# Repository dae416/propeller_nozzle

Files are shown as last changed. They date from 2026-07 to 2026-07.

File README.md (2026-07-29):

# Squid-Inspired Jet Nozzle Dataset

Thrust and power measurements for **24 propeller-driven jet nozzle designs**
across three generations — **32 measurements**, because every Generation 1 shape
was tested in both rigid and flexible material. Printable geometry included.

Generation 1 is a Latin-hypercube sweep of the design space. Generations 2 and 3
were proposed by a multi-objective Bayesian optimizer (ARD Matérn-5/2 GP + qEHVI)
trained on everything measured before them, maximizing thrust while minimizing
current draw.

Nozzles come in two materials, **rigid** and **flexible**. In Generation 1 each
shape was printed in both, so the same geometry appears twice. From Generation 2
on, rigid and flexible are optimized separately — each nozzle is one material
only, with its own geometry. All were measured on a dynamometer in a water tank.

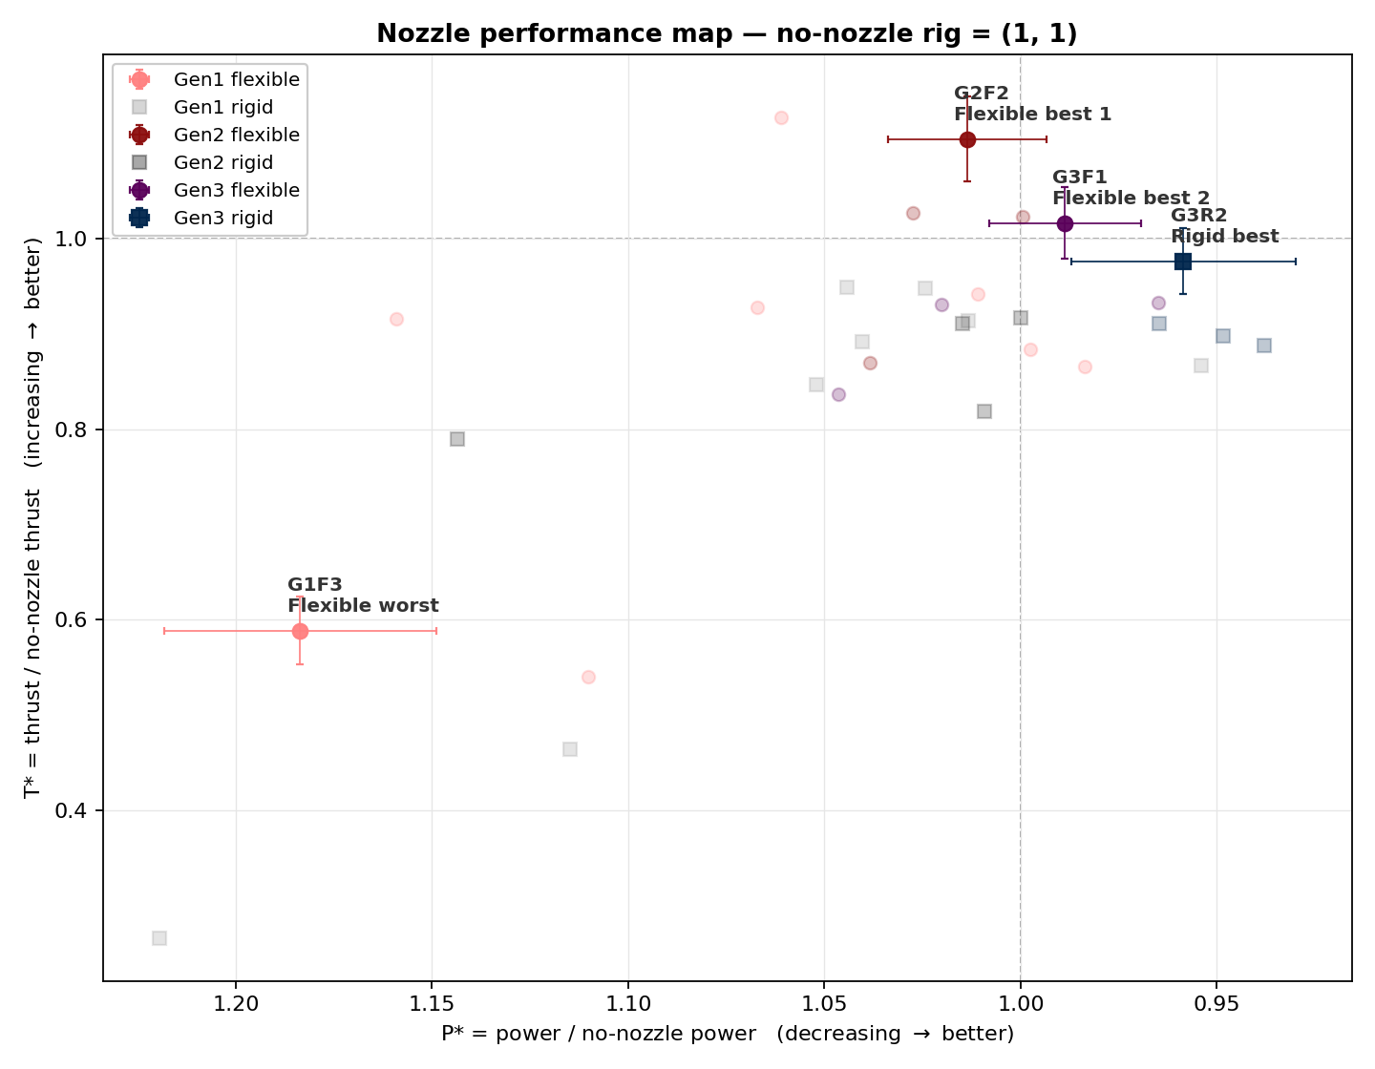
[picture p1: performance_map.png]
Nozzle performance map


The four representative shapes, with error bars over the three thrust pulses;
every other measured nozzle is behind them in faded form. Both axes are ratios
against the bare propeller, which sits at (1, 1). **Up and to the right is
better** — the power axis is reversed so that less power draw points right.
Indices for the faded points are in the results table below.

---

## Representative shapes

<table>
<tr>
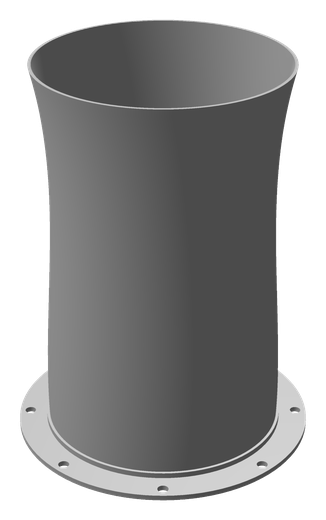
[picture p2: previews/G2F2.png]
<td width="25%" align="center"><br><b>G2F2</b><br>Flexible best 1</td>
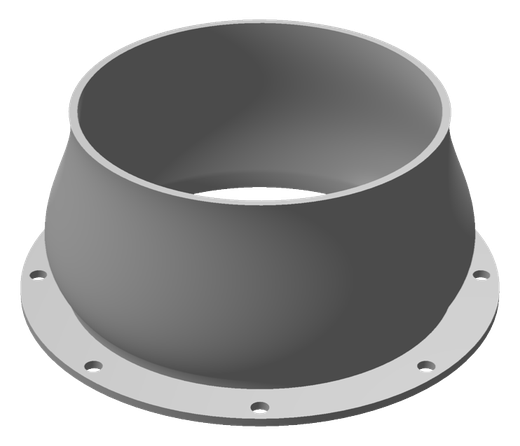
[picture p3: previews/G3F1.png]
<td width="25%" align="center"><br><b>G3F1</b><br>Flexible best 2</td>
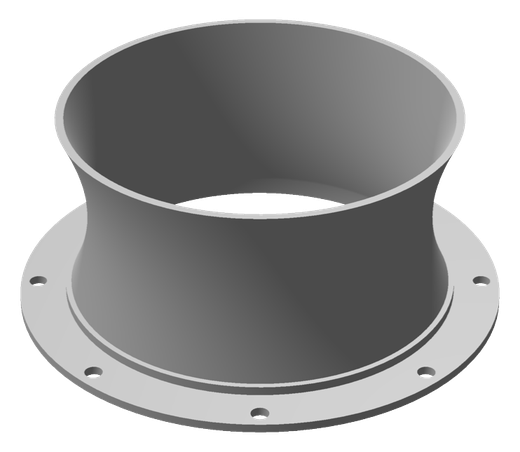
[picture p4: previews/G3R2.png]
<td width="25%" align="center"><br><b>G3R2</b><br>Rigid best</td>
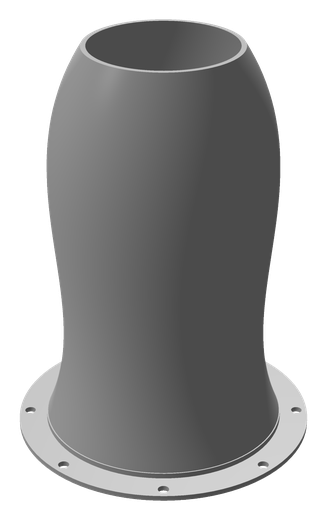
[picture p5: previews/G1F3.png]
<td width="25%" align="center"><br><b>G1F3</b><br>Flexible worst</td>
</tr>
</table>

| Index | Role | Generation | Material | Thrust vs no-nozzle | Power vs no-nozzle | STEP |
|---|---|---|---|---|---|---|
| **`G2F2`** | Flexible best 1 | 2 | Flexible | **+10.5%** ± 4.4% | **+1.4%** ± 2.0% | [`G2_F_S2.step`](STEP/G2_F_S2.step) |
| **`G3F1`** | Flexible best 2 | 3 | Flexible | **+1.7%** ± 3.8% | **-1.1%** ± 1.9% | [`G3_F_S1.step`](STEP/G3_F_S1.step) |
| **`G3R2`** | Rigid best | 3 | Rigid | **-2.3%** ± 3.4% | **-4.2%** ± 2.9% | [`G3_R_S2.step`](STEP/G3_R_S2.step) |
| **`G1F3`** | Flexible worst | 1 | Flexible | **-41.2%** ± 3.5% | **+18.4%** ± 3.5% | [`G1S3.step`](STEP/G1S3.step) |

Their shape parameters:

| Index | bulge | neck | tip_expansion | R_tip (mm) | t_bottom (mm) | t_top (mm) | L (mm) |
|---|---|---|---|---|---|---|---|
| `G2F2` | 0.9743 | 0.936 | 0.9288 | 50.2222 | 0.9466 | 1.1814 | 139.7882 |
| `G3F1` | 1.1 | 1 | 0.9167 | 46.4392 | 2 | 2 | 42.5 |
| `G3R2` | 0.8463 | 0.9246 | 0.8258 | 55.25 | 0.7 | 2 | 42.5 |
| `G1F3` | 0.8455 | 0.9322 | 0.8378 | 33.9944 | 1.5733 | 1.8579 | 145.2361 |

---

## Reading the numbers

Both metrics are ratios against the **no-nozzle** rig running in the same session:

| | meaning | good direction | 1.0 means |
|---|---|---|---|
| **T\*** | thrust ÷ no-nozzle thrust | ↑ higher | same thrust as bare propeller |
| **I\*** | current ÷ no-nozzle current | ↓ lower | same current as bare propeller |
| **P\*** | power ÷ no-nozzle power | ↓ lower | supply voltage is fixed, so P\* = I\* exactly |

**The tables below report these as percent change from the bare propeller**,
because it reads more directly: `+10.5%` thrust is T\* = 1.105, `-4.2%` power is
P\* = 0.958. So **positive thrust is good, negative power is good**. The `±` is
the standard deviation over the three pulses, also in percent. The CSVs keep the
raw ratios.

**Why normalize at all?** The rig's absolute output drifts between test sessions
by up to 20% — two Gen2 Rigid sessions measured the bare propeller at 26.9 N and
32.2 N. Yet the nozzle-to-baseline ratios in those two sessions were 0.865 and
0.853: the drift is in the rig, not in the nozzles. Dividing it out is what makes
generations comparable. Which no-nozzle run backs each session was chosen per
session by the experimenter, from the recorded data.

The consequence is that **T\* and I\* compare across the whole table, but raw
newtons would not** — which is why raw values are not published here. The
`Session` column records which no-nozzle run each row was divided by.

---

## Results

⭐ marks a representative shape. Sorted by thrust within each group.

**Gen1 Flexible**

| Index | Thrust | Power | Session | STEP |
|---|---|---|---|---|
| `G1FCylinder` | +12.8% ± 3.7% | +6.1% ± 6.8% | G1 | — |
| `G1F6` | -5.7% ± 1.5% | +1.1% ± 8.7% | G1 | [`G1S6.step`](STEP/G1S6.step) |
| `G1F2` | -7.2% ± 3.4% | +6.7% ± 5.2% | G1 | [`G1S2.step`](STEP/G1S2.step) |
| `G1F1` | -8.3% ± 8.9% | +15.9% ± 15.3% | G1 | [`G1S1.step`](STEP/G1S1.step) |
| `G1F8` | -11.6% ± 4.1% | -0.2% ± 4.1% | G1 | [`G1S8.step`](STEP/G1S8.step) |
| `G1F5` | -13.4% ± 2.2% | -1.6% ± 3.0% | G1 | [`G1S5.step`](STEP/G1S5.step) |
| `G1F3` ⭐ | -41.2% ± 3.5% | +18.4% ± 3.5% | G1 | [`G1S3.step`](STEP/G1S3.step) |
| `G1F4` | -46.0% ± 1.1% | +11.0% ± 5.2% | G1 | [`G1S4.step`](STEP/G1S4.step) |

**Gen1 Rigid**

| Index | Thrust | Power | Session | STEP |
|---|---|---|---|---|
| `G1RCylinder` | -5.0% ± 1.8% | +4.4% ± 4.7% | G1 | — |
| `G1R2` | -5.2% ± 3.0% | +2.4% ± 4.0% | G1 | [`G1S2.step`](STEP/G1S2.step) |
| `G1R5` | -8.6% ± 2.7% | +1.3% ± 5.1% | G1 | [`G1S5.step`](STEP/G1S5.step) |
| `G1R8` | -10.8% ± 2.2% | +4.0% ± 4.7% | G1 | [`G1S8.step`](STEP/G1S8.step) |
| `G1R6` | -13.3% ± 3.5% | -4.6% ± 4.6% | G1 | [`G1S6.step`](STEP/G1S6.step) |
| `G1R1` | -15.3% ± 5.0% | +5.2% ± 7.2% | G1 | [`G1S1.step`](STEP/G1S1.step) |
| `G1R4` | -53.7% ± 1.5% | +11.5% ± 1.7% | G1 | [`G1S4.step`](STEP/G1S4.step) |
| `G1R3` | -73.5% ± 0.8% | +21.9% ± 5.7% | G1 | [`G1S3.step`](STEP/G1S3.step) |

**Gen2 Flexible**

| Index | Thrust | Power | Session | STEP |
|---|---|---|---|---|
| `G2F2` ⭐ | +10.5% ± 4.4% | +1.4% ± 2.0% | G2F | [`G2_F_S2.step`](STEP/G2_F_S2.step) |
| `G2F1` | +2.8% ± 3.4% | +2.8% ± 1.1% | G2F | [`G2_F_S1.step`](STEP/G2_F_S1.step) |
| `G2F3` | +2.3% ± 0.4% | -0.0% ± 5.2% | G2F | [`G2_F_S3.step`](STEP/G2_F_S3.step) |
| `G2F4` | -13.0% ± 3.7% | +3.8% ± 3.3% | G2F | [`G2_F_S4.step`](STEP/G2_F_S4.step) |

**Gen2 Rigid**

| Index | Thrust | Power | Session | STEP |
|---|---|---|---|---|
| `G2R3` | -8.3% ± 3.7% | -0.0% ± 3.6% | G2R_S34 | [`G2_R_S3.step`](STEP/G2_R_S3.step) |
| `G2R2` | -8.9% ± 2.2% | +1.5% ± 3.8% | G2R_S12 | [`G2_R_S2.step`](STEP/G2_R_S2.step) |
| `G2R1` | -18.1% ± 1.3% | +0.9% ± 2.5% | G2R_S12 | [`G2_R_S1.step`](STEP/G2_R_S1.step) |
| `G2R4` | -21.0% ± 3.8% | +14.3% ± 2.1% | G2R_S34 | [`G2_R_S4.step`](STEP/G2_R_S4.step) |

**Gen3 Flexible**

| Index | Thrust | Power | Session | STEP |
|---|---|---|---|---|
| `G3F1` ⭐ | +1.7% ± 3.8% | -1.1% ± 1.9% | G3F | [`G3_F_S1.step`](STEP/G3_F_S1.step) |
| `G3F2` | -6.7% ± 1.8% | -3.5% ± 4.1% | G3F | [`G3_F_S2.step`](STEP/G3_F_S2.step) |
| `G3F4` | -6.9% ± 2.3% | +2.0% ± 1.0% | G3F | [`G3_F_S4.step`](STEP/G3_F_S4.step) |
| `G3F3` | -16.3% ± 3.1% | +4.6% ± 4.1% | G3F | [`G3_F_S3.step`](STEP/G3_F_S3.step) |

**Gen3 Rigid**

| Index | Thrust | Power | Session | STEP |
|---|---|---|---|---|
| `G3R2` ⭐ | -2.3% ± 3.4% | -4.2% ± 2.9% | G3R | [`G3_R_S2.step`](STEP/G3_R_S2.step) |
| `G3R1` | -8.9% ± 2.9% | -3.5% ± 2.2% | G3R | [`G3_R_S1.step`](STEP/G3_R_S1.step) |
| `G3R3` | -10.2% ± 3.6% | -5.2% ± 2.2% | G3R | [`G3_R_S3.step`](STEP/G3_R_S3.step) |
| `G3R4` | -11.2% ± 1.4% | -6.2% ± 1.5% | G3R | [`G3_R_S4.step`](STEP/G3_R_S4.step) |

---

## Files

| File | Content |
|---|---|
| [`nozzle_performance.csv`](nozzle_performance.csv) | 32 rows — the table above, machine-readable |
| [`geometry_parameters.csv`](geometry_parameters.csv) | 7 shape parameters per nozzle, same 32 rows, same `Index` |
| [`STL/`](STL) | 23 printable geometries |
| [`STEP/`](STEP) | The same 23 geometries as faceted B-rep STEP solids (see note below) |
| [`stl_to_step.py`](stl_to_step.py) | Script that regenerates `STEP/` from `STL/` |
| [`previews/`](previews) | Renders of the representative shapes |
| [`performance_map.png`](performance_map.png) | The plot at the top of this page |
| [`make_plot.py`](make_plot.py) | Script that regenerates the plot from the CSV |

### Columns

| Column | Meaning |
|---|---|
| `Index` | `G<generation><material><shape>` — e.g. `G1F3` is Generation 1, Flexible, shape 3. Joins the two CSVs 1:1 |
| `Generation` | 1–3 |
| `Type` | `R` rigid, `F` flexible |
| `Session` | Which no-nozzle run this row was normalized against; rows sharing a session are the most directly comparable |
| `T_star`, `I_star`, `P_star` | Normalized thrust, current, power (see above) |
| `*_std` | Standard deviation over the three pulses, normalized |
| `STL_File` | Geometry in `STL/` |
| `Representative` | Set for the four shapes highlighted above |

### Geometry parameters

| Parameter | Unit | Meaning |
|---|---|---|
| `bulge` | – | Mid-body radial expansion factor |
| `neck` | – | Throat contraction factor |
| `tip_expansion` | – | Outlet flare factor |
| `R_tip_mean_mm` | mm | Mean outlet radius |
| `t_bottom_mm`, `t_top_mm` | mm | Wall thickness at inlet / outlet |
| `L_mm` | mm | Nozzle length |

All nozzles share a fixed mounting interface: 85 mm inner bore, 110 mm flange,
2 mm flange thickness, 8 × ⌀4 mm bolts on a 51 mm circle.

### STEP files

The nozzles exist natively as meshes, so the `STEP/` files are **faceted B-rep
solids** — every STL triangle sewn into a closed `MANIFOLD_SOLID_BREP`
(~52 MB each). These import as solids in CATIA, SpaceClaim, NX, Creo, and
FreeCAD. An earlier revision shipped compact AP242 *tessellated* STEP
(~1.7 MB each) instead, but CATIA and SpaceClaim rejected those with
*"No B-Rep data in input file"*, so the heavy-but-universal form is committed.
`python stl_to_step.py STL/ out/` regenerates the tessellated variant if you
want the small files. Requires `pip install cadquery-ocp`.

### Flexible material — Formlabs Flexible 50A Resin

Flexible nozzles were printed in [Formlabs Flexible 50A Resin](https://formlabs.com/products/flexible-50a-resin/),
a soft translucent SLA elastomer for parts normally made of soft rubber or
silicone. Post-cured properties:

| Property | Value |
|---|---|
| **Stress at 100% elongation** | **1.7 MPa** ← the key stiffness number for these nozzles |
| Shore hardness | 55A |
| Ultimate tensile strength | 3.4 MPa |
| Stress at 50% elongation | 0.9 MPa |
| Elongation at break | 160% |
| Tear strength | 12.3 kN/m |
| Compression set (70°C, 22 h) | 3.1% |

---

## Notes

- **Only Generation 1 shares geometry between materials.** `G1R3` and `G1F3` are
  the same printed shape in different material, so they carry identical parameter
  rows and point at the same STL. Generation 2 and 3 nozzles are each a single
  material with geometry of their own — `G2F1` and `G2R1` are unrelated shapes.
  The optimizer runs one GP per material, trained only on that material's data.
- **`Cylinder`** is a plain reference tube, not an optimizer output, and has no
  STL. In flexible material it out-thrusts every shaped Generation 1 nozzle
  (T\* = 1.127) — worth knowing before reading too much into the early sweep.
- **Shape 7** of the Generation 1 sweep was never tested, so the indices skip
  from 6 to 8.
- **32 rows are 32 physical nozzles but only 24 distinct geometries.** Each
  Generation 1 shape was printed in both materials, so its 8 shapes account for
  16 rows. Generation 2 and 3 contribute 8 rows and 8 geometries each.
- **Generation 3 Rigid** numbers come from a 2026-05-06 processing run whose raw
  dynamometer files are no longer in the source project, so they cannot currently
  be recomputed from scratch.

## License

Measurement data and geometry from a DARPA-funded study of squid-inspired
propulsion. Please contact the repository owner before reuse.

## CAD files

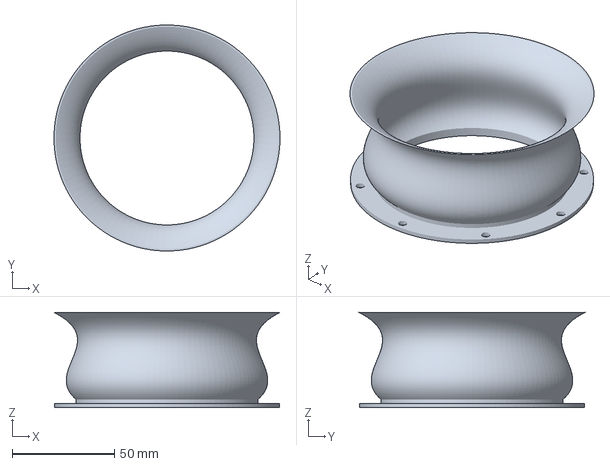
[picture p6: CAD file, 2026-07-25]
STEP/G3_R_S3.step
110.5 x 110.5 x 46.5 mm

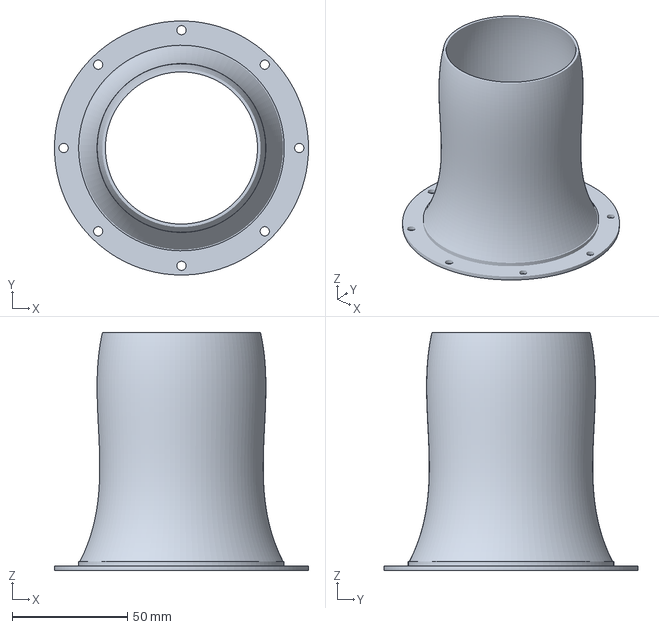
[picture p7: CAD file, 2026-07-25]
STEP/G1S1.step
110.0 x 110.0 x 103.1 mm

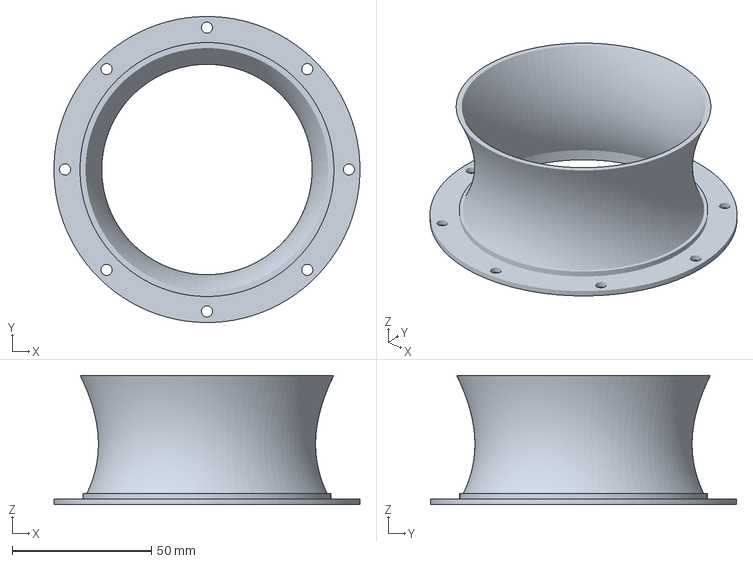
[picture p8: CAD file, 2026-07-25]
STEP/G3_R_S2.step
110.0 x 110.0 x 46.5 mm

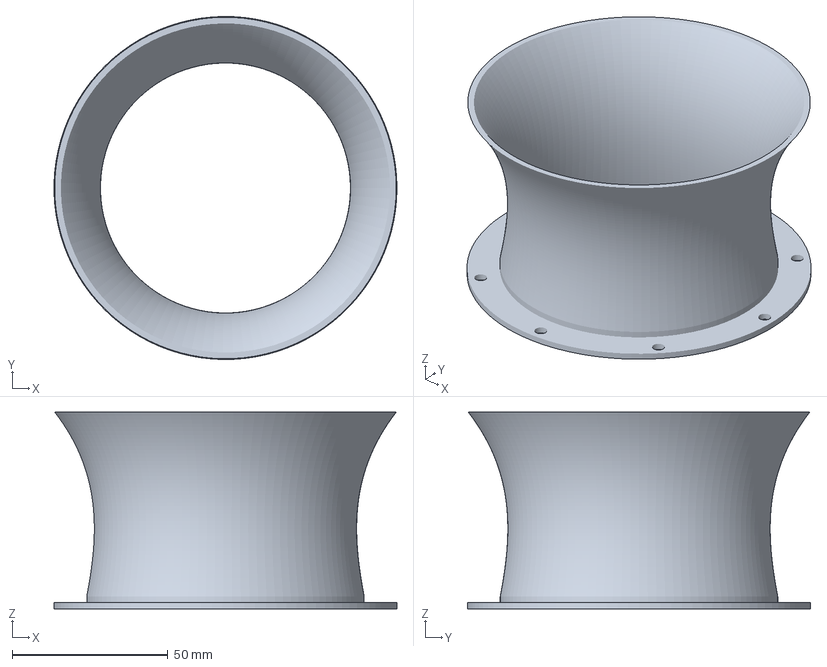
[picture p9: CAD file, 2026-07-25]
STEP/G2_F_S1.step
110.0 x 110.0 x 63.0 mm

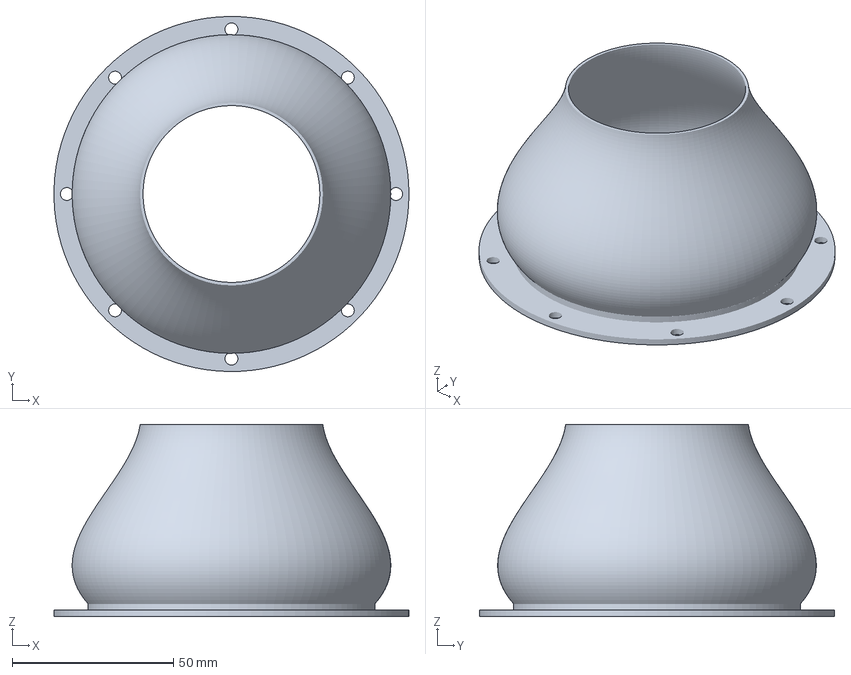
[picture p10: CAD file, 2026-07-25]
STEP/G1S4.step
110.0 x 110.0 x 59.6 mm

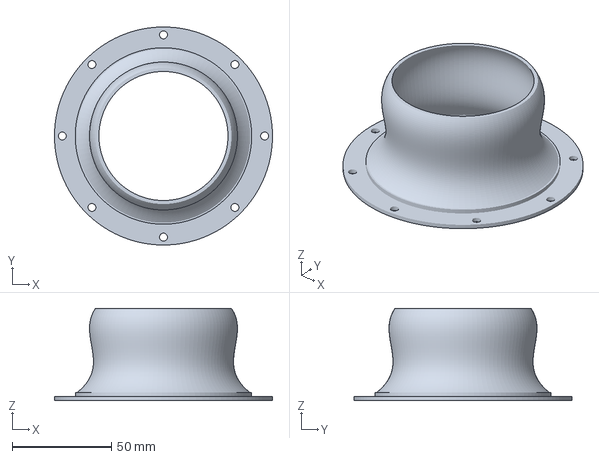
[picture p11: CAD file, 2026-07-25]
STEP/G2_R_S4.step
110.0 x 110.0 x 46.5 mm

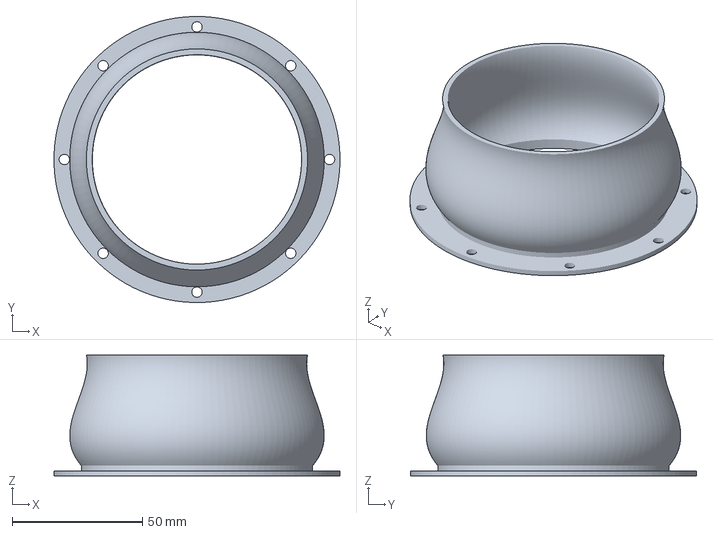
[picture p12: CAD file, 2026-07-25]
STEP/G3_F_S1.step
110.0 x 110.0 x 46.5 mm

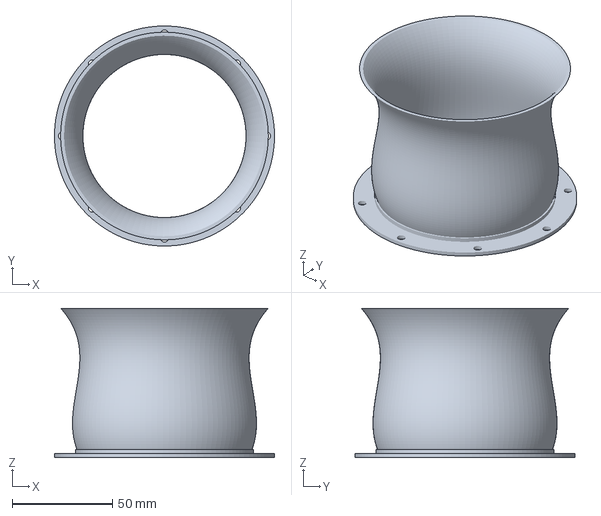
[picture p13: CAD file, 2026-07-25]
STEP/G1S6.step
110.0 x 110.0 x 74.7 mm

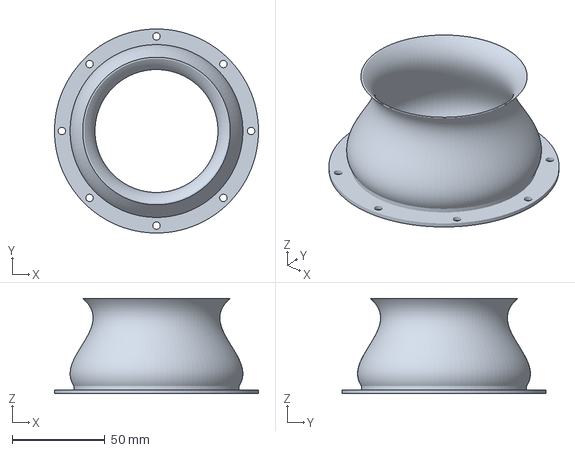
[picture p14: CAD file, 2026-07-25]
STEP/G3_R_S1.step
110.0 x 110.0 x 51.3 mm

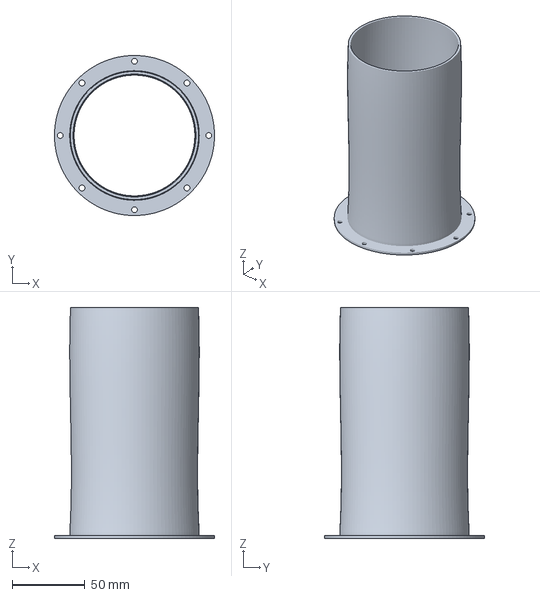
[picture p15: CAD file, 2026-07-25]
STEP/G3_F_S4.step
110.0 x 110.0 x 158.7 mm

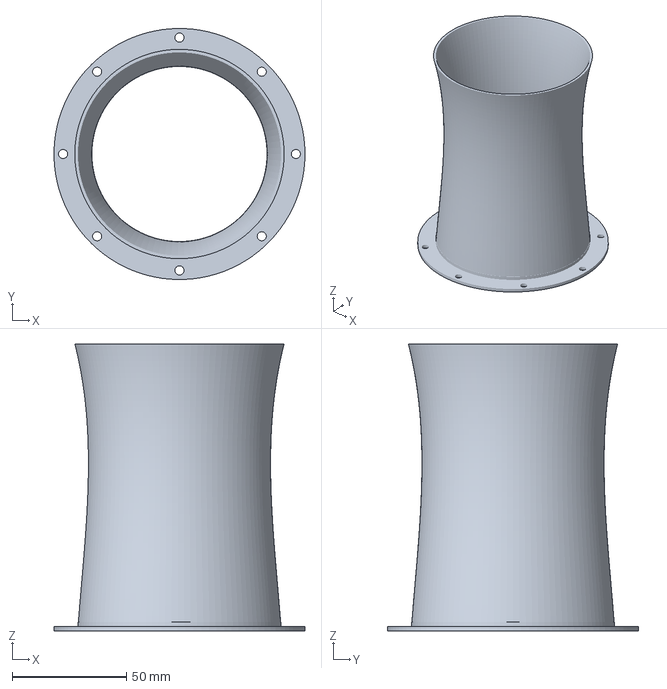
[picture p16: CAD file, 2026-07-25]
STEP/G1S8.step
110.0 x 110.0 x 125.8 mm

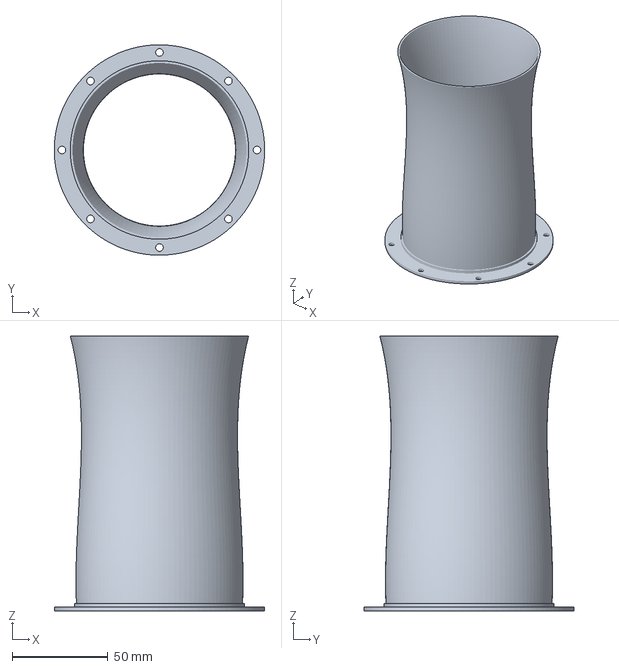
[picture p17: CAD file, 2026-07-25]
STEP/G2_F_S2.step
110.0 x 110.0 x 143.8 mm

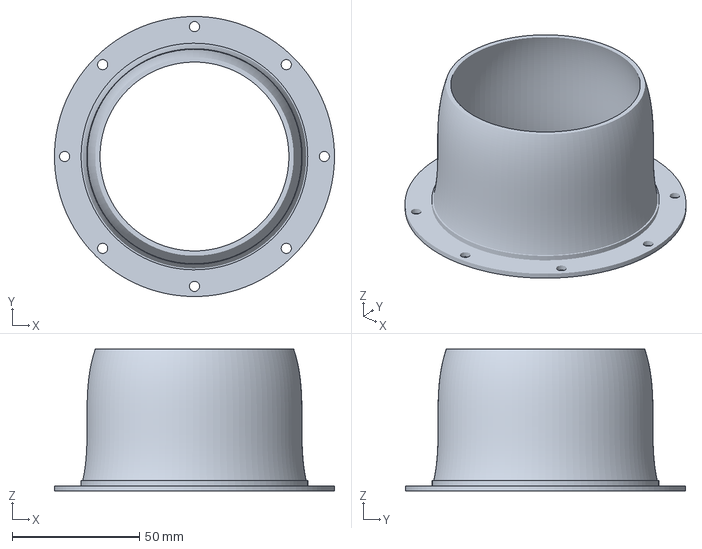
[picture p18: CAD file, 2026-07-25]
STEP/G2_F_S4.step
110.0 x 110.0 x 55.7 mm

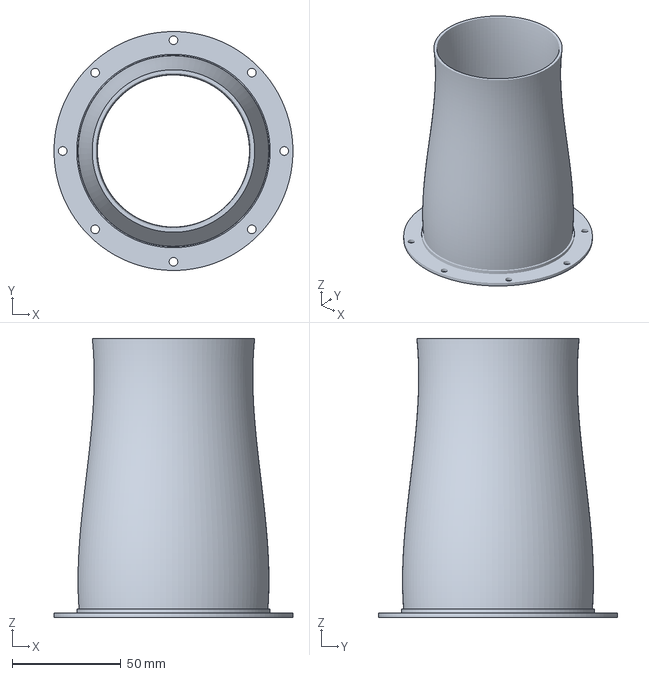
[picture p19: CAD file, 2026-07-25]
STEP/G1S5.step
110.0 x 110.0 x 128.4 mm

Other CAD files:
STEP/G2_F_S3.step
STEP/G3_F_S2.step
STEP/G3_F_S3.step
STEP/G2_R_S3.step
STEP/G1S2.step
STEP/G1S3.step
STEP/G2_R_S1.step
STEP/G2_R_S2.step
STEP/G3_R_S4.step
STL/G1S1.stl
STL/G1S2.stl
STL/G1S3.stl
STL/G1S4.stl
STL/G1S5.stl
STL/G1S6.stl
STL/G1S8.stl
STL/G2_F_S1.stl
STL/G2_F_S2.stl
STL/G2_F_S3.stl
STL/G2_F_S4.stl
STL/G2_R_S1.stl
STL/G2_R_S2.stl
STL/G2_R_S3.stl
STL/G2_R_S4.stl
STL/G3_F_S1.stl
STL/G3_F_S2.stl
STL/G3_F_S3.stl
STL/G3_F_S4.stl
STL/G3_R_S1.stl
STL/G3_R_S2.stl
STL/G3_R_S3.stl
STL/G3_R_S4.stl

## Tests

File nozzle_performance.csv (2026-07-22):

Index | Generation | Type | Session | T_star | T_star_std | I_star | I_star_std | P_star | P_star_std | STL_File | Representative
G1F1 | 1 | F | G1 | 0.9165 | 0.0894 | 1.159 | 0.1531 | 1.159 | 0.1531 | G1S1.stl
G1F2 | 1 | F | G1 | 0.9281 | 0.0344 | 1.0671 | 0.0522 | 1.0671 | 0.0522 | G1S2.stl
G1F3 | 1 | F | G1 | 0.5885 | 0.0353 | 1.1836 | 0.0347 | 1.1836 | 0.0347 | G1S3.stl | Flexible worst
G1F4 | 1 | F | G1 | 0.5398 | 0.0114 | 1.1103 | 0.0517 | 1.1103 | 0.0517 | G1S4.stl
G1F5 | 1 | F | G1 | 0.8658 | 0.0218 | 0.9837 | 0.03 | 0.9837 | 0.03 | G1S5.stl
G1F6 | 1 | F | G1 | 0.9426 | 0.0149 | 1.0109 | 0.0869 | 1.0109 | 0.0869 | G1S6.stl
G1F8 | 1 | F | G1 | 0.884 | 0.0406 | 0.9976 | 0.0408 | 0.9976 | 0.0408 | G1S8.stl
G1FCylinder | 1 | F | G1 | 1.1275 | 0.0373 | 1.0611 | 0.0676 | 1.0611 | 0.0676
G1R1 | 1 | R | G1 | 0.8468 | 0.0501 | 1.052 | 0.0722 | 1.052 | 0.0722 | G1S1.stl
G1R2 | 1 | R | G1 | 0.9482 | 0.0295 | 1.0244 | 0.0399 | 1.0244 | 0.0399 | G1S2.stl
G1R3 | 1 | R | G1 | 0.2647 | 0.0085 | 1.2194 | 0.0566 | 1.2194 | 0.0566 | G1S3.stl
G1R4 | 1 | R | G1 | 0.4633 | 0.0146 | 1.1148 | 0.0171 | 1.1148 | 0.0171 | G1S4.stl
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

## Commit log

2026-07-21 Add squid-inspired jet nozzle dataset (Gen1-Gen3)
    32 measured nozzles: normalized thrust (T*), current (I*) and power (P*),
    each divided by the no-nozzle baseline of its own measurement session.
    Includes 7 shape parameters per nozzle, 23 printable STLs, and renders of
    the four representative shapes.
    [G1S1.stl, G1S2.stl, G1S3.stl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]
2026-07-21 Add performance map plot; fix material description
    T* vs P* scatter with error bars and per-nozzle index labels. Power axis is
    reversed so less power draw points right, matching the MATLAB plots.
    Only Generation 1 shapes were printed in both materials; from Generation 2 on
    each nozzle is a single material with its own geometry.
2026-07-21 Add Generation 4 Flexible; new representative shapes
    G4F1-G4F4 measured data and geometry from the flexible-line project, with
    their own no-nozzle baseline. 32 -> 36 nozzles, 23 -> 27 STLs.
    Representatives are now G2F2 (flexible best 1) and G3F1 (flexible best 2);
    G3R2 and G1F3 unchanged.
    [G4_F_S1.stl, G4_F_S2.stl, G4_F_S3.stl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]
2026-07-21 Restore the original per-session baselines
    Reverts the same-session baseline substitution for G2F and G3F. Which
    no-nozzle run backs each session was chosen from the recorded data by the
    experimenter; the pipeline's original choice stands.
    G3F I* moves back below 1 (G3F1: 1.040 -> 0.989), matching the MATLAB plots.
    [nozzle_performance.csv]
2026-07-22 Show the other nozzles as faded context on the map
2026-07-22 Exclude Generation 4 from the dataset
    Back to 32 measured nozzles (24 distinct geometries) and 23 STLs across
    Generations 1-3. Notes now spell out that Gen1 shapes count twice because
    they were printed in both materials.
    [G4_F_S1.stl, G4_F_S2.stl, G4_F_S3.stl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]
2026-07-22 Report thrust and power as percent change
2026-07-25 Add STEP geometry (AP242 tessellated), Flexible 50A material properties, STEP links in README
    [G1S1.step, G1S2.step, G1S3.step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]
2026-07-29 Replace tessellated STEP with faceted B-rep solids
    CATIA and SpaceClaim rejected the AP242 tessellated STEP files with
    "No B-Rep data in input file" and imported nothing. Regenerated all 23
    files with stl_to_step.py --brep: each STL triangle sewn into a closed
    MANIFOLD_SOLID_BREP (~52 MB/file). Verified by re-import: every file
    reads back as exactly one solid.
